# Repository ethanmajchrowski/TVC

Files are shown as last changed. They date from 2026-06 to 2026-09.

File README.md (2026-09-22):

# Two-Axis Thrust Vector Control Model Rocket

A model rocket featuring a two-axis thrust-vector-control (TVC) system, custom flight computer, embedded control software, and a Python flight simulation for controller development and pre-flight testing.

<!-- ![TVC Assembly](Videos/motion.gif) -->
<div align="center">
  <br>
  <i>Two-axis gimbal actuation test. Both axes are commanded with a sinusoidal function.</i>
</div>

## Project Documentation
This project is documented using a design notebook format, recording engineering decisions, prototypes, testing, failures, and design integration in chronologically organized notebooks. 

| Subsystem | Documentation |
| --- | --- |
| Mechanical | [Mechanical Design Notebook](docs/mechanical/README.md)
| Electronics | [Electronics Design Notebook](docs/electronics/README.md)
| Simulation | [Simulation Design Notebook](docs/simulation/README.md)
| Testing | [Testing & Validation](docs/testing/README.md)

A note on testing: most testing is documented in the related design log, so the testing subsection will be lightly used and possibly removed later.

---

## Project Overview

This project is an experimental model rocket designed around an active two-axis thrust-vector-control system. Rather than using aerodynamic control surfaces, the vehicle controls its attitude by mechanically redirecting motor thrust.

The system consists of:

* A lightweight two-axis TVC gimbal
* XIAO ESP32C6 flight computer running MicroPython
* MPU6050 IMU and BMP280 barometer
* Servo-based gimbal actuation
* Python flight-dynamics and control simulation
* SolidWorks mechanical design and 3D-printed prototypes

The project is being developed incrementally, with mechanical design, simulation, electronics integration, and ground testing preceding flight testing.

---

## Current Status

### Completed

* [x] Two-axis TVC gimbal mechanical design
* [x] SolidWorks parts and assembly
* [x] PETG gimbal assembly
* [x] XIAO ESP32C6 flight computer integration
* [x] MPU6050 IMU integration
* [x] BMP280 barometer integration
* [x] Servo actuation and gimbal bench testing
* [x] Initial Python flight simulation
* [x] PID control implementation in simulation

### In Progress

* [ ] Final rocket body design
* [ ] Flight simulation
* [ ] Sensor fusion
* [ ] Electronics documentation
* [ ] Controller tuning and hardware validation
* [ ] Integrated ground testing

### Planned

* [ ] Full-system ground test
* [ ] First controlled flight
* [ ] Flight data collection
* [ ] Post-flight data analysis

---

## Technical Specifications

| Parameter | Current Specification |
| --- | --- |
| Target liftoff mass | ~250 g |
| Motor | D12-5 target; E12-6 under consideration |
| Maximum TVC angle | Approximately ±30° |
| Flight computer | Seeed Studio XIAO ESP32C6 |
| Firmware | MicroPython |
| IMU | MPU6050 |
| Barometer | BMP280 |
| Gimbal actuation | MG90S Servo motors |
| Gimbal axes | 2 |

Specifications are subject to change as the vehicle design and simulation are refined.

---

## System Architecture

The system is divided into three primary components:
<div align="center">
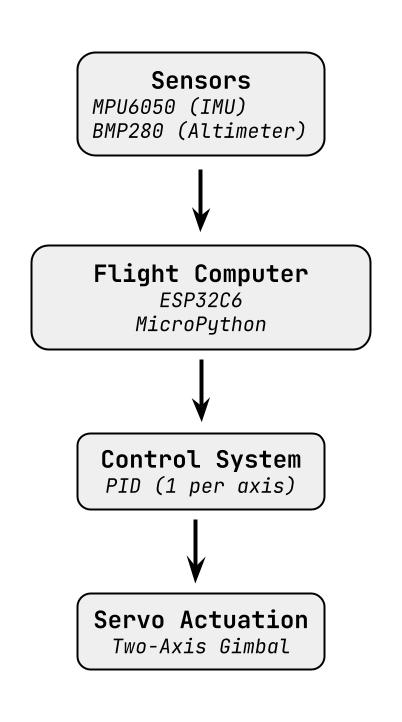
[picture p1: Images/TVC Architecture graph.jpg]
  <br>
</div>

---

## Flight Simulation
[Subsystem Page](docs/simulation/)

Flight Simulations planned to be compiled in MATLAB with Simulink. These will simulate the rocket's PID controls as well as physical status in flight, allowing PID constants to be tuned and verified before first flight.

---

## Embedded Hardware

The flight computer uses a XIAO ESP32C6 running MicroPython.

### Sensors

* **MPU6050** — inertial measurement
* **BMP280** — barometric altitude measurement

### Control

Servo actuators are commanded using PWM outputs from the ESP32C6. The embedded control software is intended to use sensor measurements to determine vehicle attitude and command the TVC servos accordingly.

Sensor-fusion and closed-loop hardware control are currently under development, and will follow this closed-loop flow:

<div align="center">
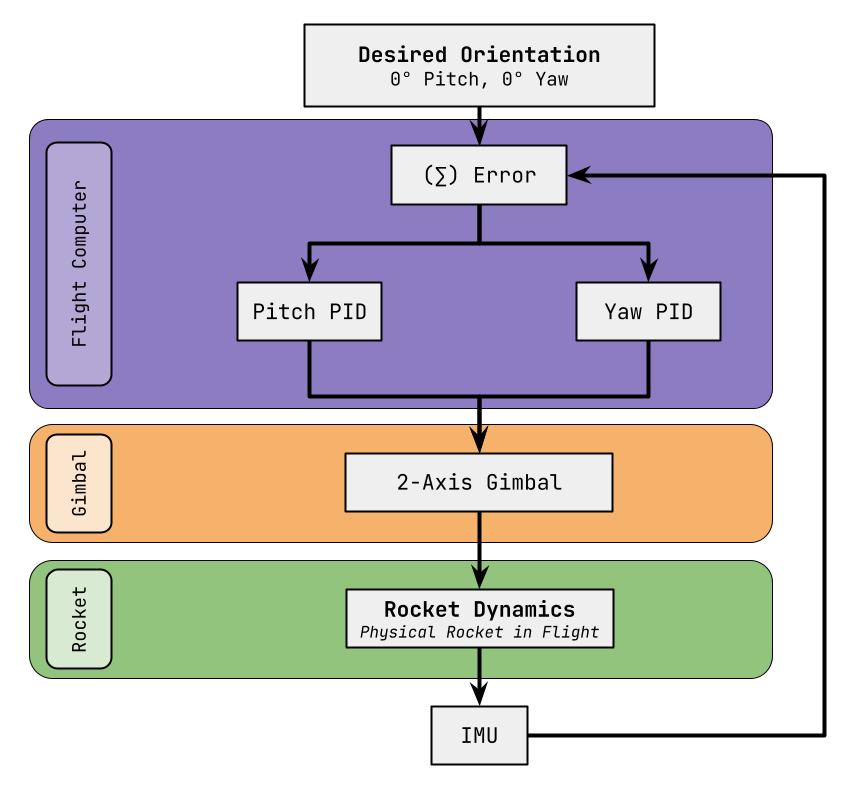
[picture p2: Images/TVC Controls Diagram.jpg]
  <br>
</div>

### Data Logging

Telemetry is currently logged to the flight computer's internal storage. The target logging rate is approximately 100 Hz, although the final rate will be determined through testing.

---

## Electronics

The flight computer is assembled on perfboard around a XIAO ESP32C6.
The design prioritizes simplicity and modularity during the prototype phase, allowing sensors and actuators to be replaced or repositioned without redesigning a PCB.

Additional documentation available in [Electronics Documentation](docs/electronics/)

---

## Repository Structure

```text
TVC/
├── docs/
│   ├── electronics/
│   ├── mechanical/
│   └── simulation/
├── CAD/
│   ├── Parts/
│   └── Assemblies/
├── Electronics/
├── Embedded/
├── Images/
├── Simulation/
└── notes.md
```

| Directory | Contents |
| --- | --- |
| `CAD/` | SolidWorks parts, assemblies, and mechanical design |
| `docs/` | Subsystem-specific documentation |
| `Electronics/` | Electronics schematics and hardware documentation |
| `Embedded/` | MicroPython flight-computer software |
| `Images/` | CAD renders, diagrams, and project photographs |
| `Simulation/`  | Python flight simulation and control software |
| `notes.md` | Development notes and design history |

---

## Development History

This project is being developed iteratively, with mechanical prototypes and simulation informing subsequent hardware revisions.

Major design iterations and test results will be documented here as development continues.

---

## Gallery

### TVC Assembly

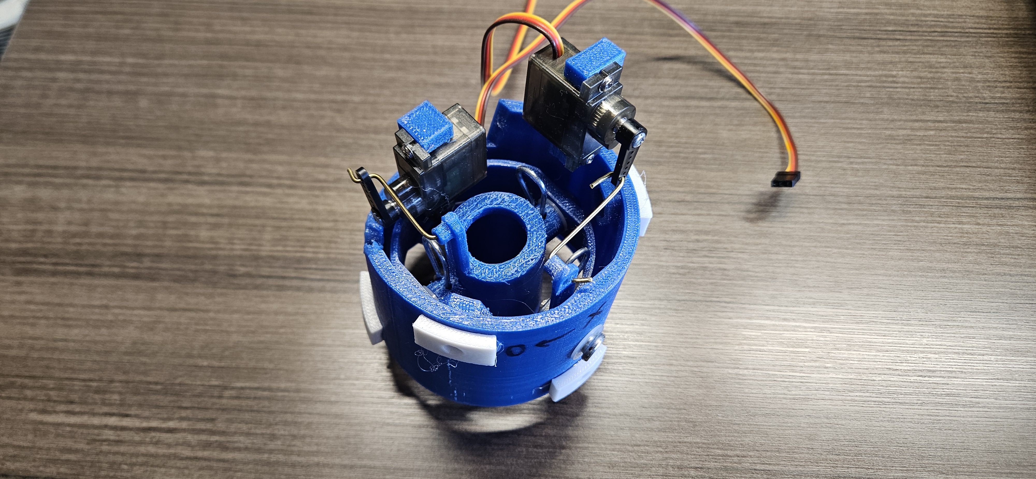
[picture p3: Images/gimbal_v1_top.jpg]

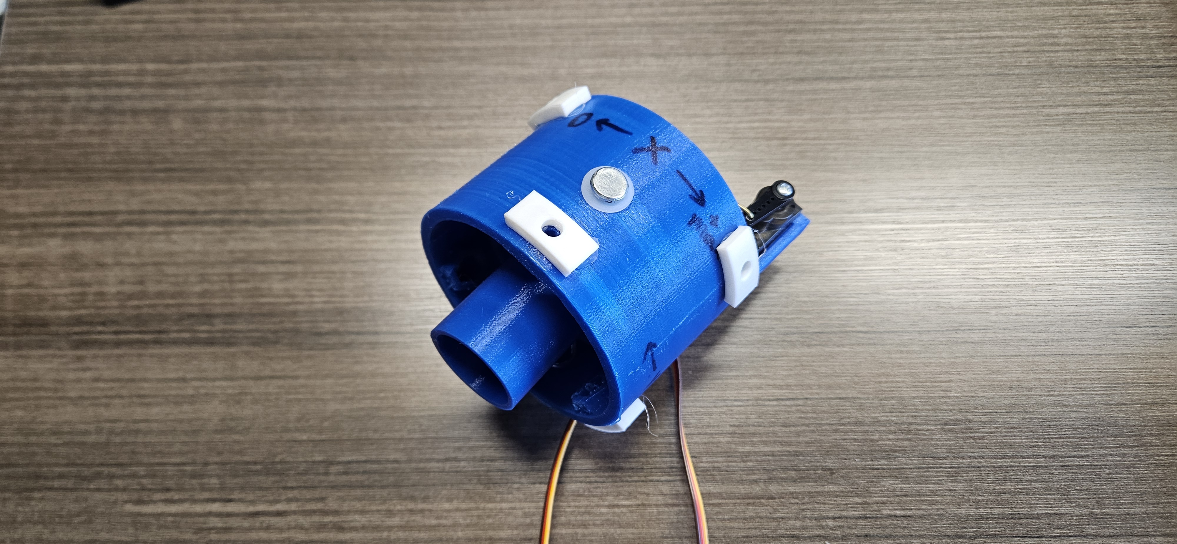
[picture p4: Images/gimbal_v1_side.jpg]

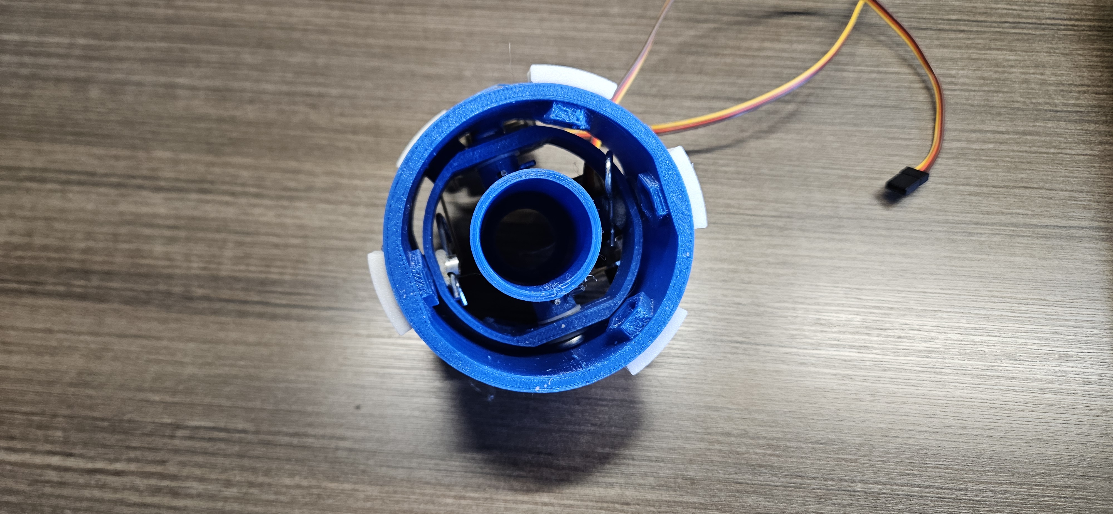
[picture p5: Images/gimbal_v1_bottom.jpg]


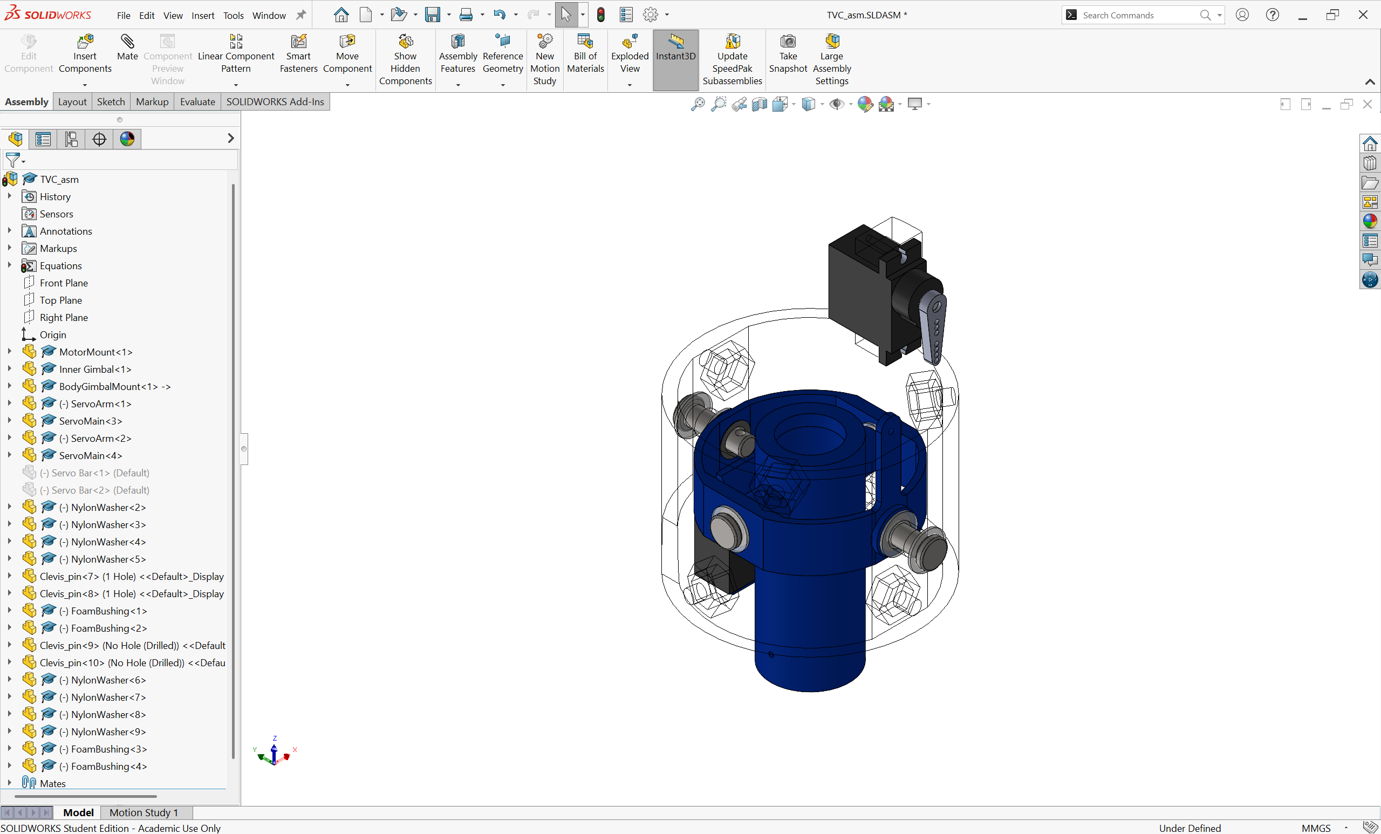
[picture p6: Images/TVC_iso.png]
TVC Isometric


*Full TVC assembly with the outer gimbal mount shown transparently.*

### Cutaway Views

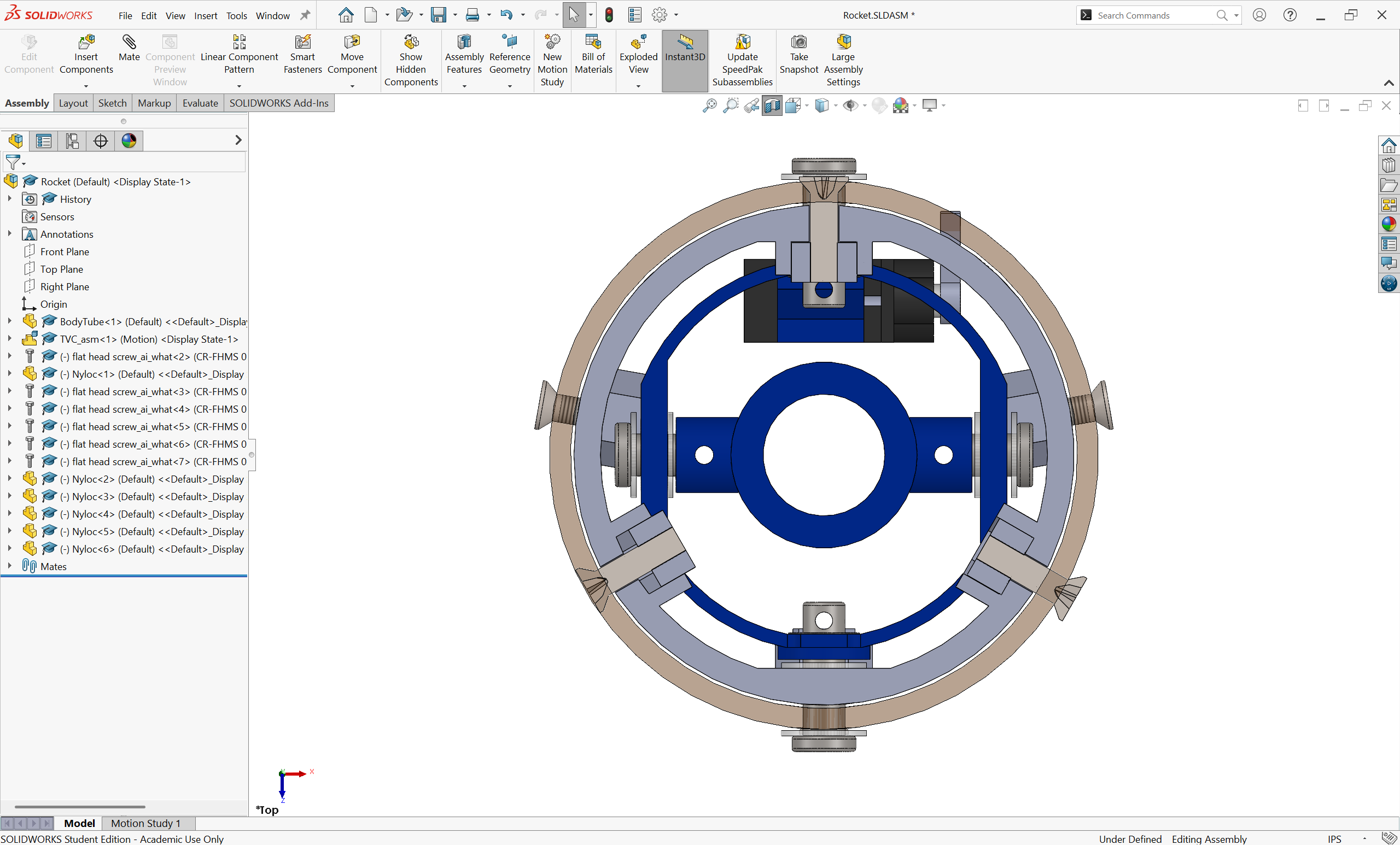
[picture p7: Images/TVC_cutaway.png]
TVC Mount Cutaway


*Gimbal mount cutaway.*

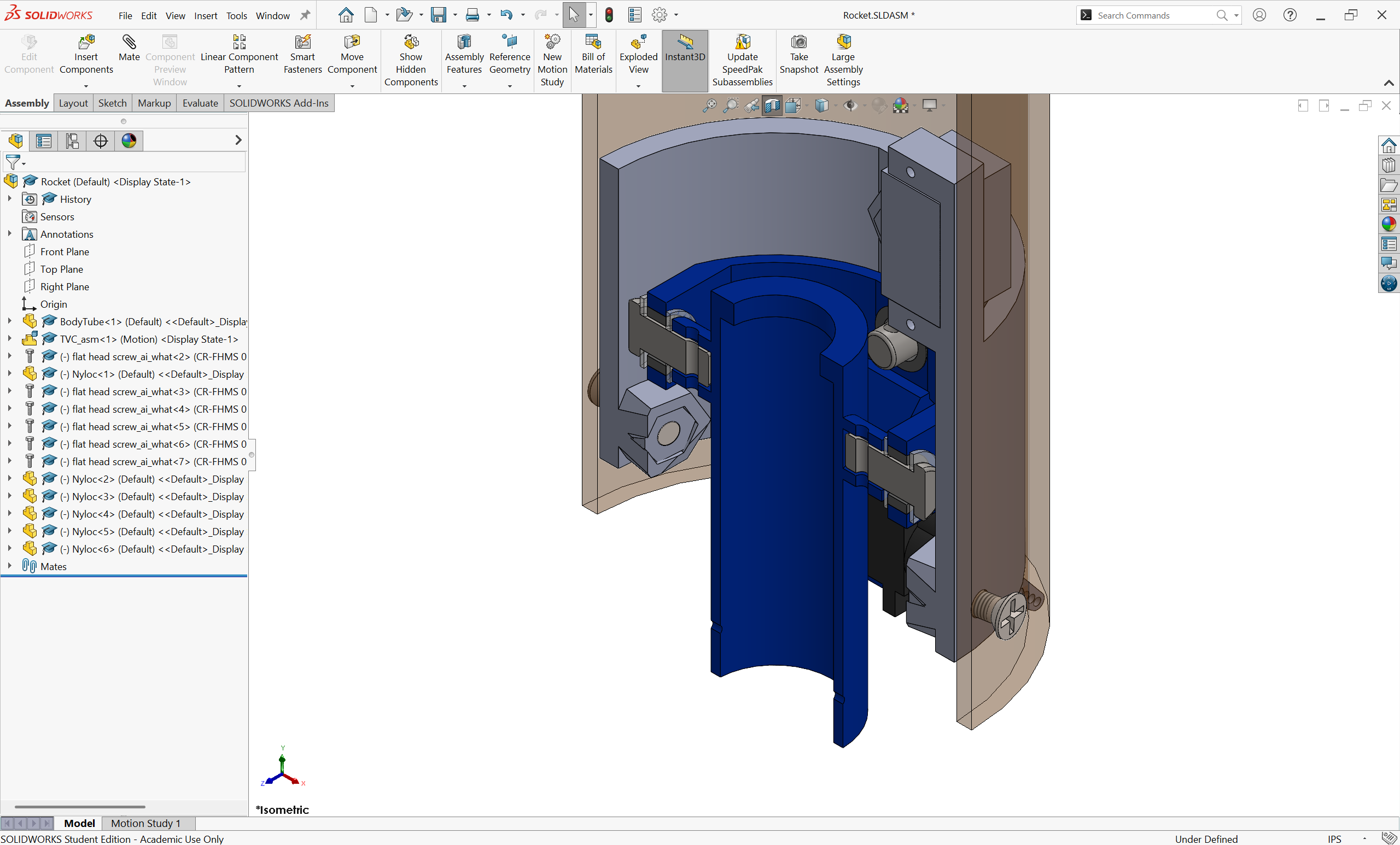
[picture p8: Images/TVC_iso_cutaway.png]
TVC Isometric Cutaway


*Isometric cutaway showing internal components and pivot hardware.*

### Hardware
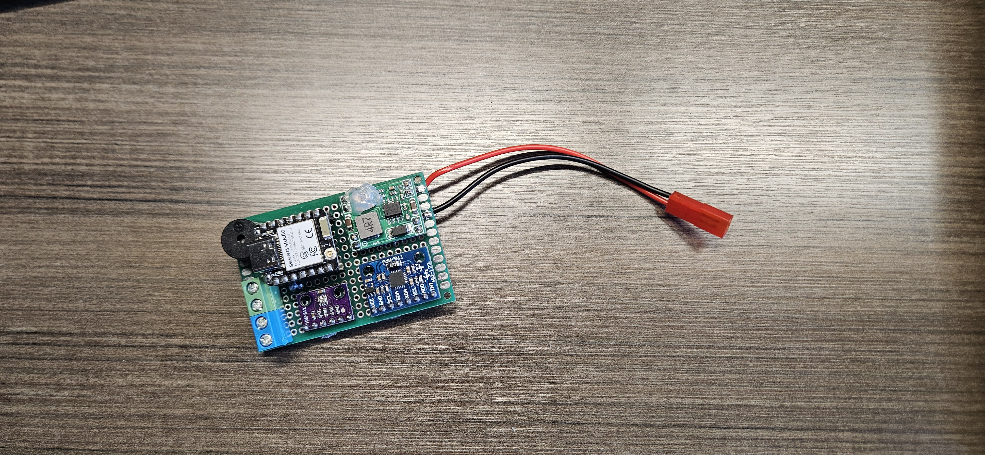
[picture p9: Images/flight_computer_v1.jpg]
Flight Computer Top

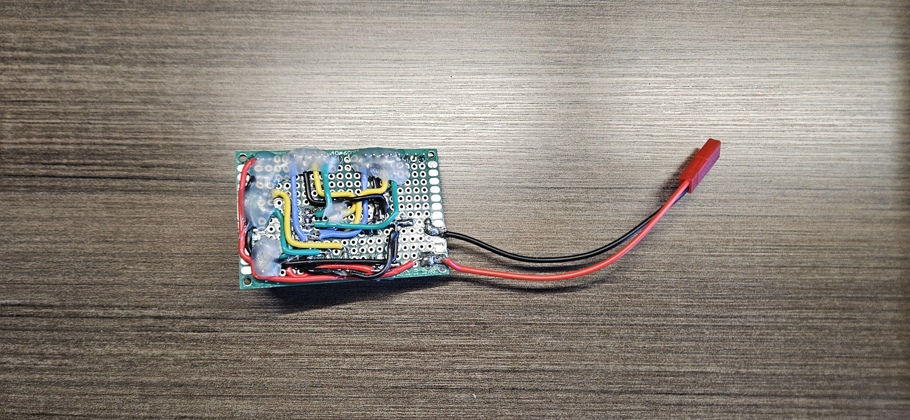
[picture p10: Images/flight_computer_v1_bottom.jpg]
Flight Computer Bottom


---

## Project Status

This is an active development project. Mechanical design, electronics integration, simulation, and control development are ongoing, and the vehicle has not yet completed controlled flight testing.

**Project To-Do**
*CAD/physical design:*
- [ ] Flight computer sled
  - [ ] Determine accessible mounting strategy for flight computer mounting hardware
- [ ] Finalize nose cone design
- [ ] Finalize body tube dimensions and mass properties
- [ ] Bulkhead
  - [ ] Determine suitable material for avionics bulkhead
  - [ ] Determine accessible mounting strategy for bulkhead
  - [ ] Determine motor ejection charge venting strategy

*Electronics:*
- [ ] MOSFET testing for ejection charge
- [ ] Ejection charge perfboard
- [ ] Documentation
  - [ ] Write about overlooking need for ejection charge

*Simulation:*
- [ ] OpenRocket finalize model
  - [ ] Figure out how to simulate rocket with artificial stability to bypass fin requirements
  - [ ] Run OpenRocket simulations to determine maximum altitude
- [ ] MATLAB physical simulation + control tuning

*Testing:*
- [ ] Thrust simulation 
  - [ ] CAD gimbal mount
  - [ ] CAD motor mount adapter for drone motor
  - [ ] Determine if rotary encoders for gimbal mount would be useful
- [ ] Ejection charge Nichrome testing
  - [ ] Ensure rapid heating
  - [ ] Check battery and electronics health
- [ ] Gimbal true angle min/maxes.

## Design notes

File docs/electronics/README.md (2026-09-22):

[← Back to project README](../../README.md)
# Electronics

## Design Requirements
The flight computer needs to:
- Read inertial measurements
- Measure barometric altitude
- Control two TVC servos
- Log flight data
- Fit within the available rocket body
- Be lightweight and serviceable
- Log data for post-flight review

---

## Entry 01 - Initial Design
Test sensors and construct a breadboard-based prototype of flight computer to verify all components and wiring architecture. Determine list of components to be included on final design.

### Design
The hardware present on the flight computer was primarily chosen due to previous possession of all sensors and controllers. These included:
- MPU 6050 IMU
- BMI 160 IMU
- BMP280 Barometer
- ESP32 XIAOC6 Microcontroller
- Arduino Nano Microcontroller

A pack of perfboard bases contained 40x60mm boards and 50x70mm boards. For size footprint, smaller was better for this project, so the 40x60mm board was targeted. 

Deciding on hardware was relatively simple: 
- The ESP32 has a much smaller footprint (21x17.5mm) versus the Nano (45x18mm), making it more suitable for the small size footprint of the targeted board.
- BMI 160 is a more modern sensor with less noise and more accurate readings than the MPU 6050.
The BMP280 was the sensor I had on-hand for altitude measurements.

The ESP32 will communicate over I2C to the IMU and altimeter, allowing both chips to only require 4 pins total on the ESP32. The ESP32 only has 10 data out pins.
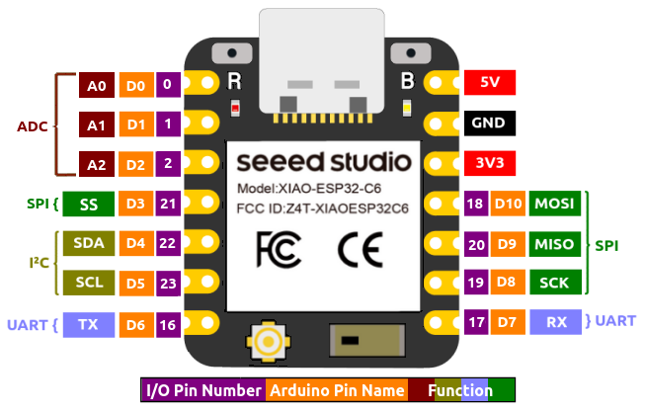
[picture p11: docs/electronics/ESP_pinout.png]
ESP Pinout


The wiring diagram is as follows:
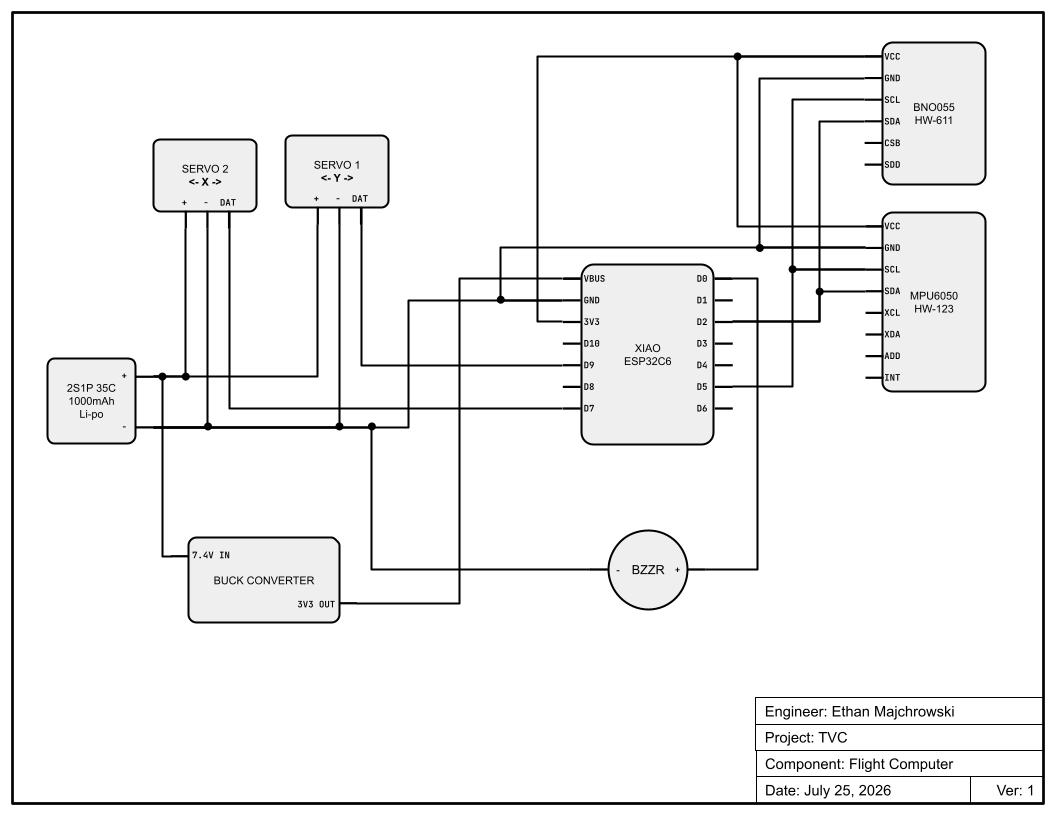
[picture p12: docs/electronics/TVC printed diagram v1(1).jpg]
Circuit Diagram


The ESP32 has a data line to both servos, which are then connected to the battery for power. The entire circuit including the battery shares a common ground. 

The battery for this build was chosen due to it's light weight and small profile. Large LiPos are too heavy and have excess capacity than needed for this build. For flying the flight computer without servos, a smaller battery could be substituted in for a smaller footprint. Since the chosen battery is 7.4V, a buck converter is needed to drop this to 5V for the ESP32 to input.

The initial buck converter chosen is a LM2596 DC to DC buck converter with a 3.0-40V to 1.5-35V adjustable range. However, these modules are large and bulky, so a more modern MP1584EN 4.5V-28V input to 0.8V-20V output adjustable converter was chosen. 

LM2596: 43.2 x 21.2mm
MP1584EN: 22.3 x 17mm

The converter has a potentiometer present to adjust the output voltage. This was set using a multimeter to confirm an output voltage of 5V.

A buzzer is also included in the design to allow for status communication when the rocket is assembled and ready to launch.

## Entry 02 - Perfboard Assembly
After all components were assembled and tested on a breadboard, they could be assembled on a perfboard. This uses holes to mount through hole components, so breakout boards and other large components can easily be soldered. 22 AWG single core wire was used to route connections between the components. The gauge was chosen to be stiff and not easily tangle or fall out of place after soldering. Single core wire is more likely to make one solid connection when soldered vs. stranded wire where a loose strand could make a faulty connection and short the board out. 

## Entry 03 - Software
The ESP32 runs MicroPython as firmware and runs one main code file. Python was chosen due to my proficiency in the language, and that this project is not one focused on learning programming concepts. Using PID control from robotics, a PID class was brought in to simplify development and reuse existing code. 

Existing libraries are used to communicate over I2C to the sensors & servos, and a pin is defined for the buzzer. These libraries allow the board to communicate with the sensors with an easy-to-use API. 

```py
class Pins: # Create pin mappings for easier reference based on physical printings on ESP32
    D0, D1, D2 = 0, 1, 2
    D3, D4, D5 = 21, 22, 23
    D6, D7 = 16, 17
    D8, D9, D10 = 19, 20, 18

# Setup I2C using builtin MicroPython module
SDA = Pin(Pins.D2)
SCL = Pin(Pins.D5)
i2c = SoftI2C(sda=SDA, scl=SCL, freq=100000)

# Sensors
# BMI180: 
  # https://github.com/DanielBustillos/bmi160-micropython-driver/tree/main
  # Authored by Daniel Bustillos
# BMP280: 
  # https://github.com/dafvid/micropython-bmp280
  # Authored by David Stenwall

imu = BMI180(i2c)
bmp = BMP280(i2c, use_case=BMP280_PRES_OS_16)

print(f"devices set up! i2c scan: {i2c.scan()}")

# Servos and maximum degrees
x_servo = Servo(Pins.D7)
x_servo_max = 100
y_servo = Servo(Pins.D9)
y_servo_max = 130
buzzer = Pin(Pins.D0, Pin.OUT)
```

The entry point for the code uses a master `FlightController` class, which exposes a `run()`function for the main code (`boot.py`) to run when the board is powered up. MicroPython runs boot.py on every power up, so any code in there will run immediately. For launches, setup and run code will be placed here.

Software to-do:
- [ ] Implement state machine to interpret ready, ascent, coast, apogee, and descent.

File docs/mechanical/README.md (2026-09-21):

[← Back to project README](../../README.md)
# Mechanical Design

Mechanical components were designed in SolidWorks with an emphasis on minimizing mass while maintaining sufficient stiffness and range of motion for the TVC mechanism.

The gimbal components form two perpendicular rotational axes, allowing the motor thrust vector to be redirected in both pitch and yaw.

**Current Development Status:** V1 gimbal assembled and ready for airframe integration.

--- 

# Design Log

## Entry 01 - Research & Prototyping
### Goal
Research existing solutions for inspiration and to develop an understanding of gimbal mechanism.

### Research
Thrust Vector Control (TVC) is a solution employed by nearly all 'real' rockets. Rather than using fins to stabilize a rocket's flight, the thrust itself can be gimbaled to exert a torque, allowing active control to keep the rocket stable.

TVC is not limited to rocketry. It can also be found on aircraft and drones. In rocketry it is especially helpful because it allows us to control the orientation of a craft without relying on fins. Fins keep a rocket stable but rely on high dynamic pressure. A simple computation for dynamic pressure (q) is $q = \frac{1}{2} \rho v^{2}$, where $\rho$ is the fluid density of the air and $v$ is the velocity of the rocket. For large rockets with low thrust to weight ratios, this velocity is very low, leading to a proportional decrease in dynamic pressure. 
*[NASA](https://www.grc.nasa.gov/www/BGH/dynpress.html), [Richard Nakka](https://www.nakka-rocketry.net/RD_fin.htm)*

The goal for this rocket is to use TVC to actively stabilize the rocket, without passive stability mechanisms like fins. To do so, a gimbal needs to be constructed. The first step was to research existing solutions to this problem.

TVC has been done on the model scale before, and designs exist to construct your own. However, for this project the design will be custom. To get an idea for how to design this gimbal, I first explored existing solutions:
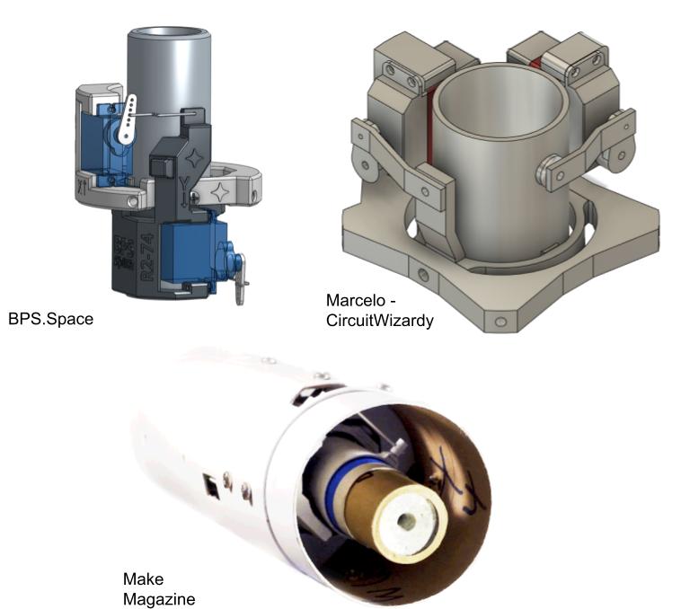
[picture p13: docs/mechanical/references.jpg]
Images of existing TVC CAD designs


These solutions highlight a few major design points:
- The mounts typically use servo motors to orient the motor
- There are 3 main components: the outer mount which fixes to the airframe, an inner gimbal which provides one axis of freedom, and a motor mount which has the second axis of rotation. 
- Sometimes, the airframe is modified to make clearance for servo arms or moving components. 

### Understanding the Gimbal
The gimbal is the most important part of this design, so it is important to develop a strong intuition for what it is doing in the mechanism, and how the parts move in relation to each other. To do this, I developed a basic prototype in SolidWorks to mock up what the motion of the gimbal should look like. 
Gimbal mock-up gif
This mockup had some issues with constraints and motion, but it provided the baseline for understanding how the inner gimbal and motor mounts should move together. One thing that was important to understand was that one servo is fixed with the airframe, and the other moves with the inner gimbal mount. This allows the axis of rotation of the second servo to follow along as the first servo moves. 

When creating this mockup, a few things were noted:
- The static servo will need a connection higher up on the inner gimbal than where the gimbal pivots, to allow room for the servo mounting
- The largest challenge with this design will be clearance to allow as much range of motion as possible. 

## Entry 02 - Designing the Gimbal
### Goal
To create a more complete, manufacturable version of the gimbal mount that can be assembled for installation into the rocket.

### Design Requirements
Taking the preliminary mockup of motion into account, the design was developed oriented based on the axes of rotations. Working outwards in, the first part to be designed is the gimbal mount which is attached to the airframe.

Requirements:
- Provide two independent rotational axes
- Allow approximately ±15° of TVC movement
- Maintain the motor's position relative to the rocket centerline
- Provide mounting locations for two servos
- Avoid interference between the gimbal, servo arms, and airframe
- Be lightweight enough for the vehicle's mass budget
- Be manufacturable using desktop 3D printing

### Outer Gimbal Mount
The outermost component is the motor gimbal mount. This design follows the internal diameter of the airframe and has a mounting bracket for the servo motor. There is also a hole for the hardware to connect to the inner gimbal mount.
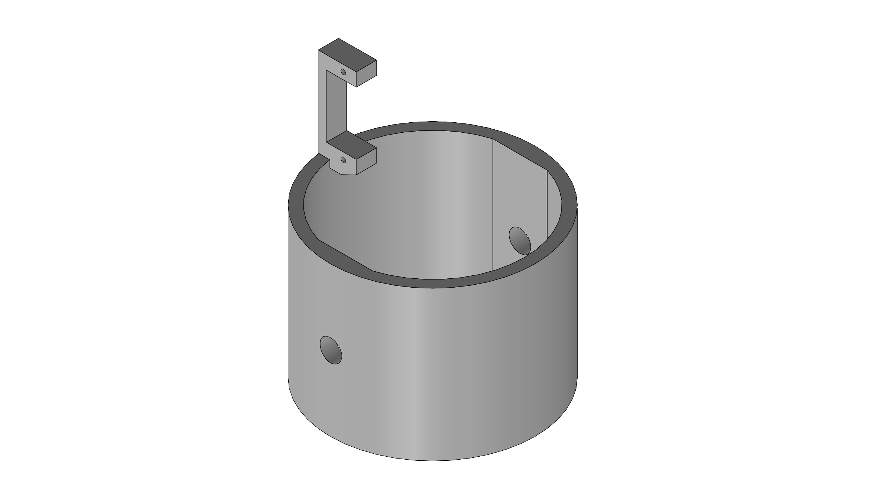
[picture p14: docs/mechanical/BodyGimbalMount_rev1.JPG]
Motor Gimbal Mount


This initial geometry follows the mock up and establishes the overall interface between the airframe and the gimbal, providing a starting point to model and attach sub components.

Design for mounting hardware also needs to be considered. This will be done using bolts and nylon locking nuts for security. 
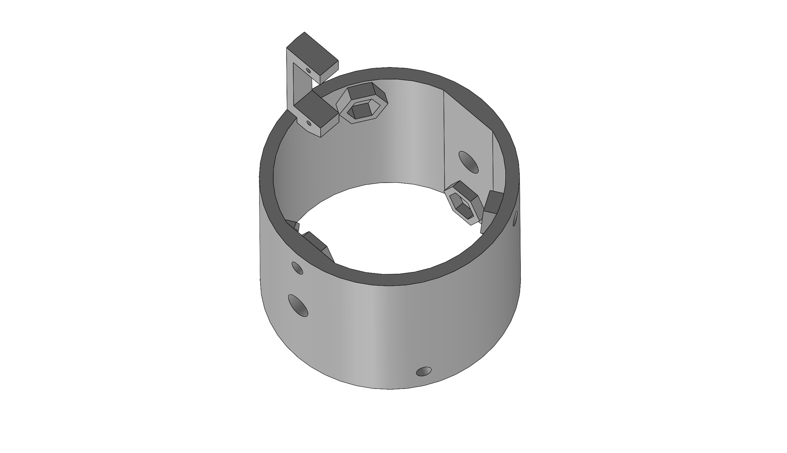
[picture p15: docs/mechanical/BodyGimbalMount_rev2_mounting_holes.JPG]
Motor Gimbal Mount

By including a hexagonal profile on the interior of the mount, the nylon nuts can be held in place with a small amount of glue and then be easily assembled with the physical slot holding the nut in place. This decision will allow for easier final assembly, where access within the gimbal is difficult.

### Inner Gimbal Mount
The inner gimbal provides the second rotational axis and carries the motor mount. Its geometry was driven primarily by three constraints:

1. Maintaining the required rotational range
2. Providing a mounting location for the second servo
3. Maintaining clearance from the outer mount throughout the range of motion

The inner gimbal was designed after the basic two-axis mechanism had been established in the preliminary SolidWorks mockup, as well as the design of the outer gimbal mount. This involved top-down part design which made it easy to define dimensions and verify clearance as geometry was added.
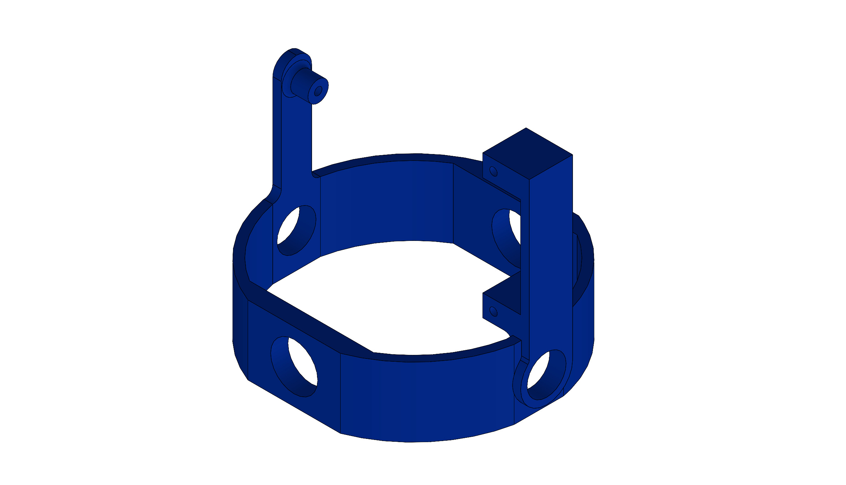
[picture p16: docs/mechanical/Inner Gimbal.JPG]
Inner Gimbal CAD

This part includes 4 axis holes for connection to the outer mount and the inner gimbal. It includes an arm to link to the outer mount servo, and another servo mount to hold the second servo.

### Motor Mount
The motor mount is the final layer of the gimbal that interfaces with the rocket motor and provides the final axis of rotation for the TVC mount. The mount needs to interface with standard Estes "Large" motors which have a 24mm OD. The initial motor-mount print used a 24.5 mm internal diameter, but the motor fit was too tight for practical assembly. The CAD dimension was increased to 25 mm for the subsequent revision. The resulting printed part measured approximately 24.75 mm internally and provided the desired fit.
The thrust is transmitted through the gimbal rotation hardware, so the motor mount includes a long sleeve to facilitate this. The sleeve around the hardware also is required because the presence of the motor makes it impossible to have hardware slot through the walls of the mount. 
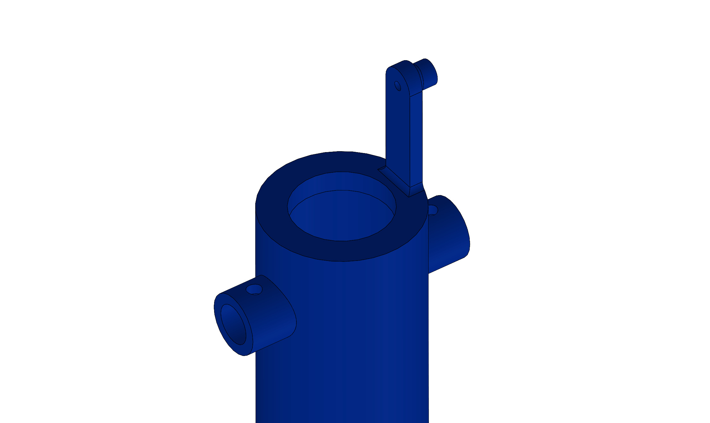
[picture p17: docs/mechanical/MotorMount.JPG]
Motor Mount CAD

A connecting arm was also included similar to the inner gimbal to allow a connection between the motor mount and servo arm. 

### Assembly Plan
The assembly of the gimbal is difficult because it requires smooth motion between 3 interconnecting parts. Dowels and rods were considered, but a clevis and cotter pin were decided on. These allow rotation around an axis (due to the clevis pin) but lock translation across that axis (due to the cotter pin).

By combining pins and the holes provided within the design we can assemble the gimbal like so:
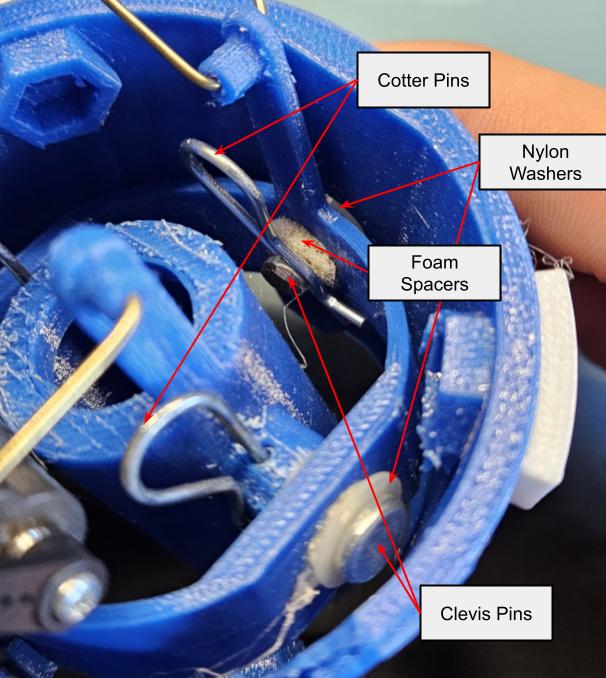
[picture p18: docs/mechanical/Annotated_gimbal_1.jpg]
Gimbal Assembly Annotated

The foam spacers help the clevis pins remain centered within the axial holes on the gimbal parts, and the nylon washers help facilitate smooth rotation between components. The assembly hardware can be seen in these cut-outs of the CAD:

TVC Mount Cutaway
TVC Isometric Cutaway

### Clearance & Range of Motion
By combining the gimbals into an assembly in SolidWorks, we can examining the range of motion of the gimbal. In initial inspection of this assembly, the clearance for the inner servo arm was very low due to the outer gimbal mount. To solve this, a slot was removed from the 3D printed component and a slot is planned to be cut in the airframe.

By moving each axis independently until a collision occurs, we can determine the approximate range of motion of the assembly:

X Axis:
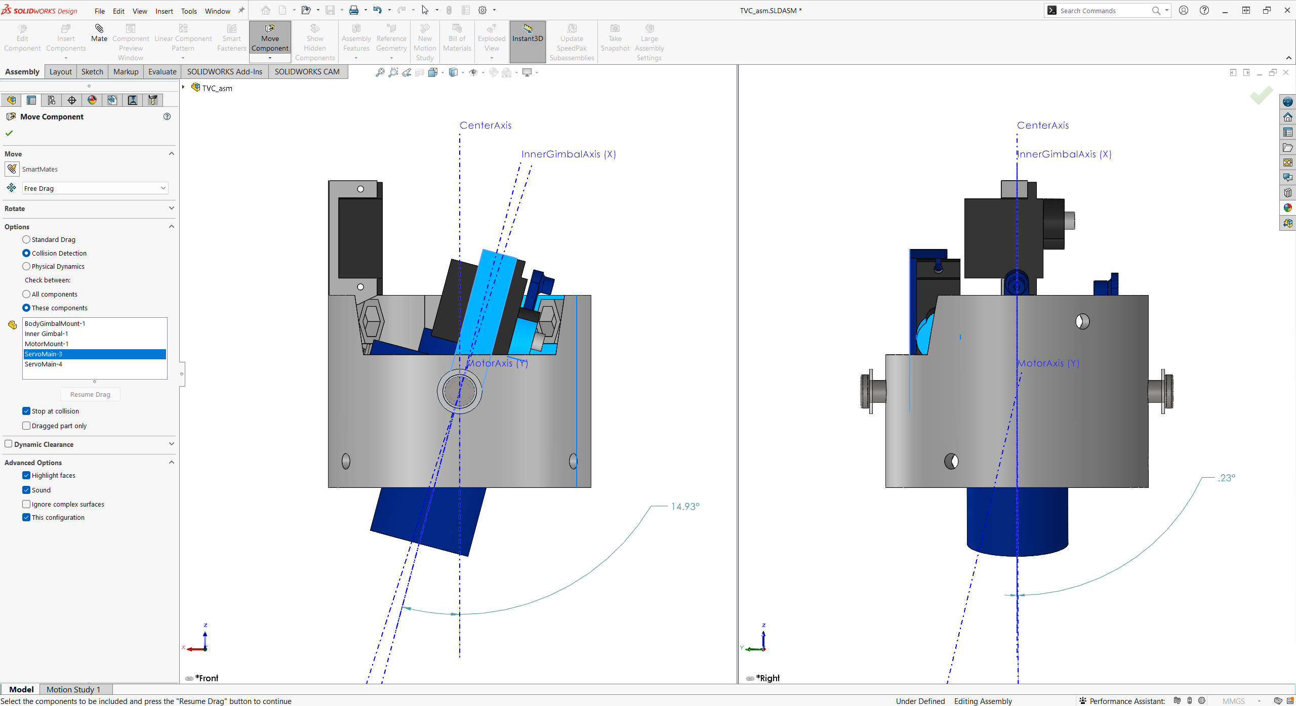
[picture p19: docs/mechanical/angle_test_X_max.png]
Gimbal Angle Testing X Max

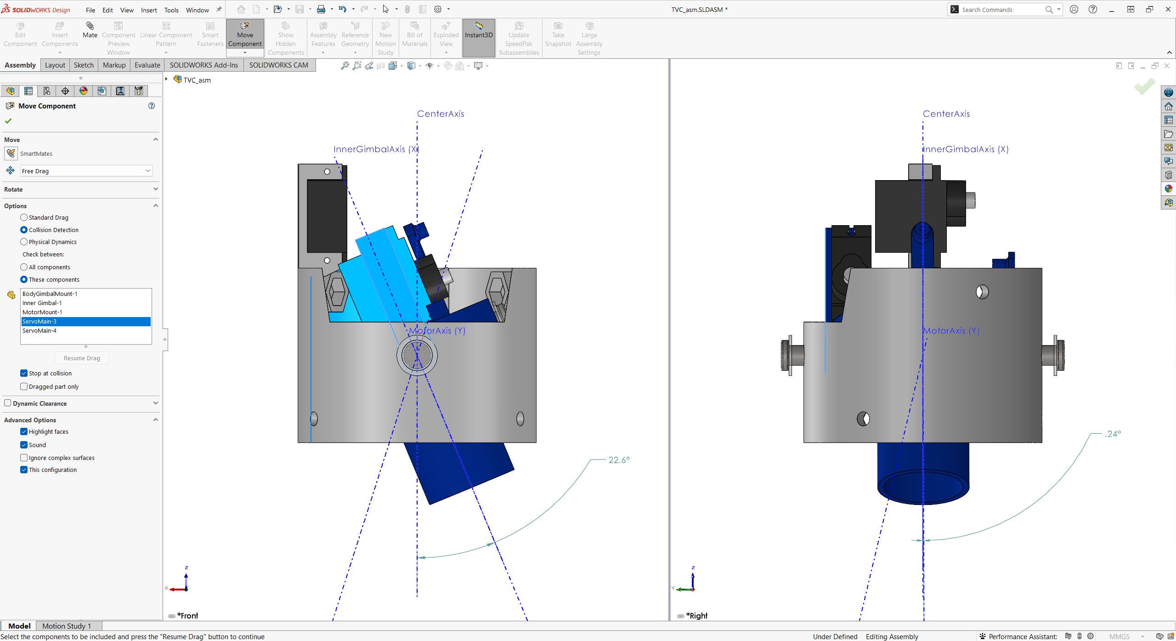
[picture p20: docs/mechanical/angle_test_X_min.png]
Gimbal Angle Testing X min

Y Axis:
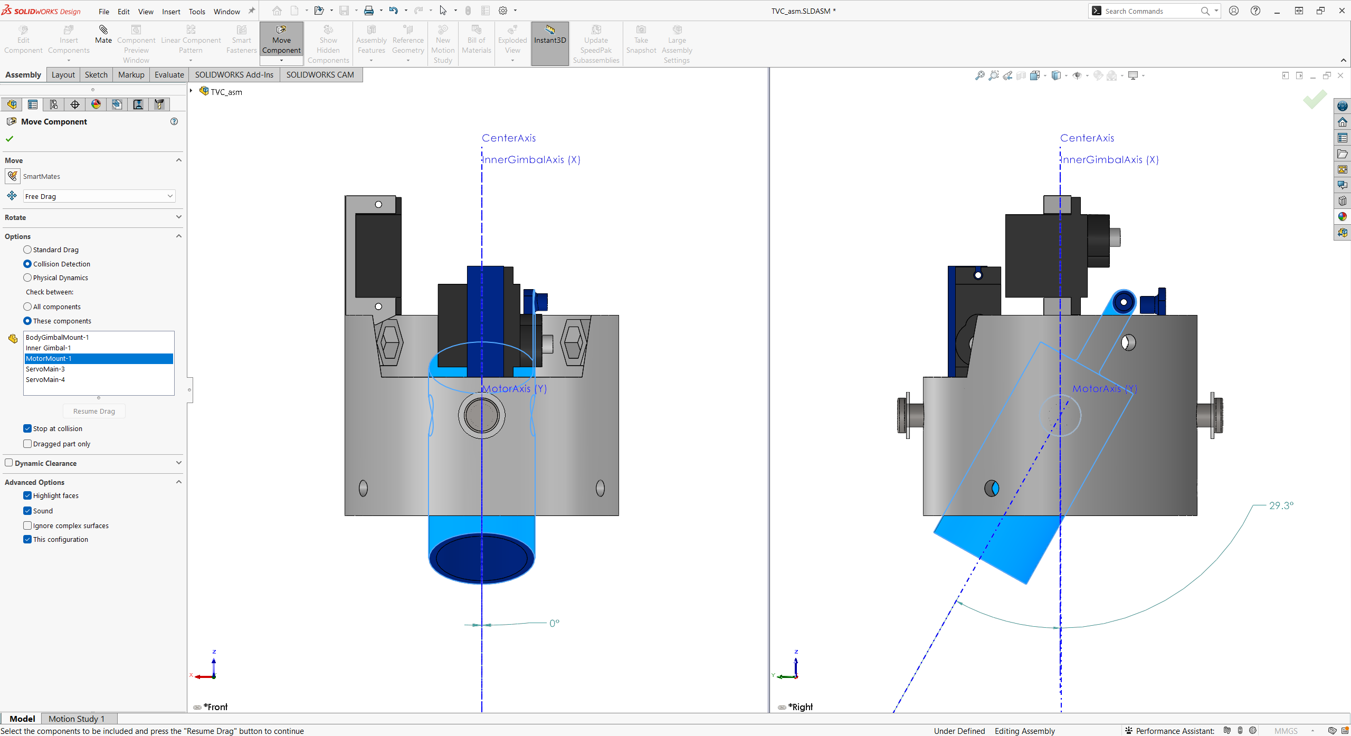
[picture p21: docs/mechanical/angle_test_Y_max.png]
Gimbal Angle Testing Y Max

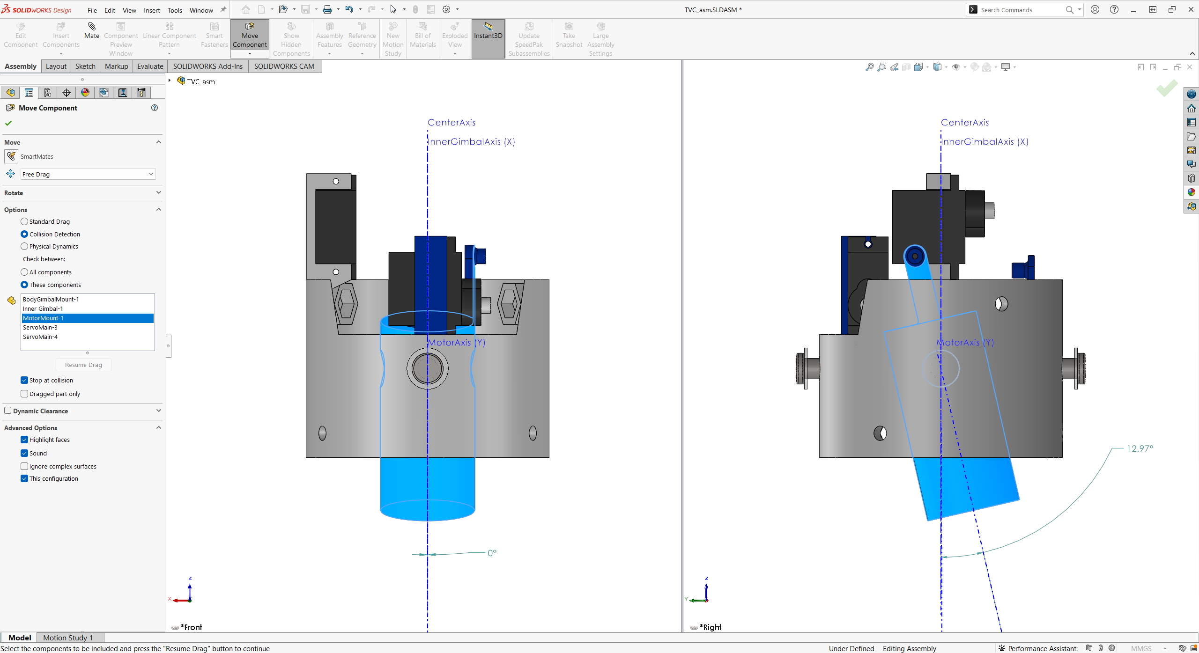
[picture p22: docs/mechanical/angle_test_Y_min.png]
Gimbal Angle Testing Y min


Based on these values, we can know the *approximate* range of motion for each gimbal axis:
| Axis | Min | Max |
| ---- | --- | --- |
| X | $-15^{\circ}$ | $+22.5^{\circ}$ |
| Y | $-30^{\circ}$ | $+13^{\circ}$ |

The limiting symmetric range is therefore approximately ±13°, although the mechanism has greater asymmetric travel in each axis. For the current design, ±15° is being treated as the nominal target range and will be validated through physical testing. With the physical assembly, modifications will be considered to increase the Y-axis limiting range by 2°.

### Materials
The initial prototype was printed and assembled in PLA Black. Due to concerns over brittleness, the current assembly is printed in PETG blue. PETG was selected for the current assembly because its greater ductility compared with PLA makes it less susceptible to brittle fracture during handling and mechanical loading.

### Final Assembly
Final Assembly Image
<div align="center">
<i> Final construction of V1 gimbal, including mounting hardware, servos, and servo linkage bars. </i>
</div>

### Initial Modifications
Shortly after initial construction, it was determined that there was significant limitation in the X - axis rotation. To fix this, the slot in the outer gimbal was expanded to make room for the inner gimbal servo arm.
Removed material highlighted in red.
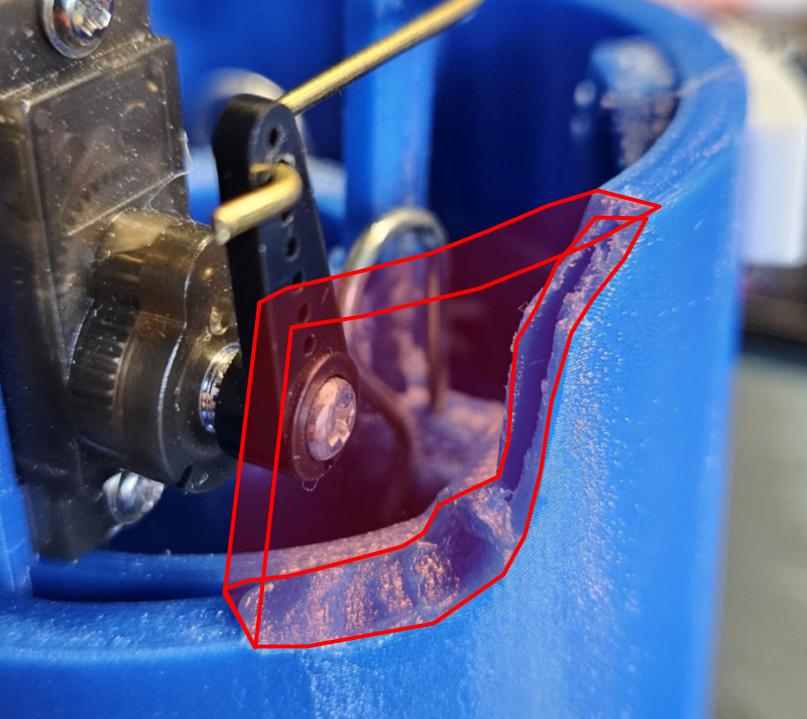
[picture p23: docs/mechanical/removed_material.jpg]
Removed Material Image

This adjustment has been updated in the CAD to reflect material removal and prevent the need from manually performing this operation in the future.

## Entry 03 - Clearance Inspection
To-do: Measure physical assembly gimbal angle limits and compare to CAD assembly theoretical limits.

## Entry 04 - Assembly V1 Evaluation
After the first assembly of the gimbal mount, observations were collected and the design was evaluated.

**Observations**
- The design has noticeable play in both rotation and translation, especially within the joint between the inner and outer gimbal components.
  - This interface likely comes from excess tolerance in the holes in the outer gimbal, allowing excess motion.
  - The motor mount is more rigid translationally but still has play rotationally. On both axes this most likely originates from imperfect linkages between servo and gimbal. 
- Upon application of upwards pressure to the motor mount (similar to the force that will be exerted by the motor) the inner gimbal translates vertically approximately 1.5mm. Gimbal motion due to servos *does not appear* to be limited by this force, but this will need to be verified with thrust simulation.
  - This allowed motion appears to flex portions of the inner gimbal outwards, most likely due to the material properties of PETG.
<div align="center">
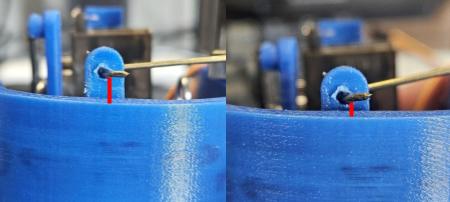
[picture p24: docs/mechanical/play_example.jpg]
     <br> <br>
</div>

- Clearance holes for airframe mounting bolts are too small, and hexagonal inserts for nylon locking nuts are too small.

<br></br>

**Potential Failure Modes**
- Component cracking
  - Due to the high force applied by the motor and inherent nature of plastic FDM printing, a major point of failure would be cracking or shattering of the gimbal mount during flight. This risk has been reduced by printing in PETG, but is not eliminated.
  - This could potentially be tested by determining the max force applied by the motor and simulating that force on the gimbal and inspecting for cracks or fractures.
- Excessive gimbal deflection
  - Excessive rotation of the gimbal due to the servo motors *could* occur, but is unlikely. Servo travel will be limited in software based on the measured mechanical range to prevent commands from driving the mechanism into known interference points.
- Pin movement
  - The play in the cotter pins introduces concern as another point of failure, but it is unlikely as the pins and clips themselves are steel. A failure of the plastic frame is much more likely.
- Servo linkage failure
  - This is a more likely point of failure for the design. The linkages between the servo arms and gimbal components could break or slip free during flight leaving the rocket without control over an axis of rotation, which would likely be catastrophic. In order to mitigate this, the ends of the linkages are bent around the connection points in a U shape to prevent disconnection.
- Mount deformation
  - Due to the heat generated by the rocket motor, the motor mount is subject to potential thermal deformation during flight, which could unpredictably degrade attitude control. While PETG has a processing melting range of 230–260°C, its structural limits are governed by its Heat Deflection Temperature (HDT) of 65–75°C (149–167°F), at which point the material softens under mechanical load. [[JLC3DP](https://jlc3dp.com/blog/petg-temperature-resistance)] Specific motor casing profiles during burns are unavailable, but thermal failure is expected to be low because the total exposure time (burn duration) is minimized, delaying localized hot spots. Post-flight inspections will monitor the mount for signs of softening, structural creep, or warping.

**Planned Revisions**
- Reduce extra clearance on clevis pin mounting holes in outer gimbal
- Move motor mount servo connection bar radially outwards to be more in line with the face of the servo to reduce play.
- If thermal deformation is found to be an issue, a cardboard or plastic liner can be used as a thermal barrier between the motor casing and mount to reduce deformation on subsequent flights.
- Increase hole and hexagonal insert diameter for airframe mounting hardware. These can be drilled out and press fit for this assembly, however.
- Add interior shoulder to inner gimbal, similar to outer shoulder on motor mount to reduce play at the clevis pin.
<div align="center">
  <image src="planned_shoulder.jpg"><br>
  <i>Notated planned shoulder addition: existing shoulder in green, location for additional shoulder in red.</i>
</div>

## Entry 05 - Airframe Design

### Initial Airframe

The initial plan for the airframe was to use the 3 in. ID cardboard tubing from my Tripoli Level 1 certification rocket. While this tubing is strong, its mass made it impractical for this project. The tubing weighed approximately **15.5 g/in.**, meaning that a roughly 2 ft. section would already exceed the maximum recommended lift weight of the selected motor before accounting for the motor, electronics, TVC assembly, and other hardware.

This prompted an investigation into lighter airframe materials.

### Fiberglass Investigation

One option considered was purchasing a pre-made fiberglass airframe. These were ultimately ruled out primarily due to cost and shipping. For example, a 30 in. section of 3 in. fiberglass tubing was priced at over $60. *[Wildman Rocketry](https://wildmanrocketry.com/collections/fiberglass-1/products/g12-3-0)*

As an alternative, I investigated manufacturing my own fiberglass body tube. This involved sourcing and preparing a mandrel, wrapping fiberglass around the mandrel, saturating the material with epoxy, and removing the cured tube from the mandrel.

The process proved to be more time-consuming than expected, particularly during removal of the cured tube from the mandrel. The resulting tube also required repair after removal and trimming. Despite these issues, the finished tube provided a useful comparison point and weighed approximately **11.58 g/in.**

### Lightweight Cardboard Alternative

During this process, I found a lightweight cardboard shipping tube with a **3.2 in. ID and 1.5 mm wall thickness**. At approximately **11 g/in.**, this tube was slightly lighter than the fiberglass tube while being significantly easier to cut, modify, and assemble.

The primary compatibility issue was the diameter of the existing TVC gimbal. The gimbal was designed around a 3 in. outer diameter, leaving a gap between the gimbal and the 3.2 in. ID airframe.

To resolve this, spacers were designed and 3D printed to attach to the outside of the gimbal and increase its effective diameter. The spacers are bonded to the gimbal rather than mechanically fastened because they do not carry the primary structural load. The existing screws retain the gimbal components, while the spacers primarily center the assembly within the airframe.

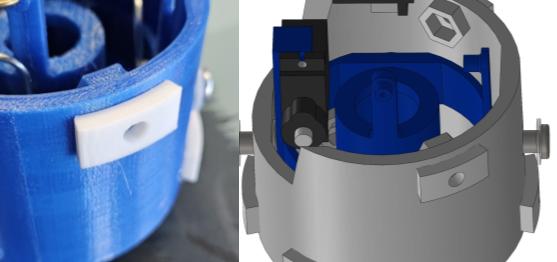
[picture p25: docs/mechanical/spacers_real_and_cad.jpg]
Airframe Spacers


*3D-printed spacers used to adapt the 3 in. gimbal assembly to the larger-diameter airframe.*

### Current Design

The lightweight cardboard tube is currently the preferred airframe material because it provides a favorable combination of low mass, low cost, and ease of fabrication compared with the alternatives investigated.

The final airframe length will be determined after the remaining rocket geometry is finalized in CAD. This will allow the overall vehicle mass to be evaluated before selecting the final length and confirming that the completed vehicle remains within the motor's appropriate performance range.

### Design Comparison

| Airframe Option | Approx. Mass | Advantages | Disadvantages |
| --- | ---: | --- | --- |
| 3 in. cardboard | 15.5 g/in. | Strong, already available | Too heavy for current mass budget |
| Homemade fiberglass |  11.58 g/in. | Lightweight, rigid | Time-consuming to manufacture; difficult demolding |
| Lightweight cardboard | ~11 g/in. | Lightweight, inexpensive, easy to modify | Larger diameter requires gimbal adaptation |

The current design therefore prioritizes the lightweight cardboard tube, with the fiberglass tube serving as an investigated alternative rather than the final material.

---

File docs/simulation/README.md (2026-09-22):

[← Back to project README](../../README.md)
# Simulation

Simulation of the rocket initially began as a custom python program to simulate the gimbal and active control of the rocket. Due to the high complexity associated with writing such a program, this approach was discarded after a time of development. Future simulation will be done in MATLAB, but tuning of the PIDs for the rocket can be done using physical testing.

---

## Python Simulation
The flight simulation was written in Python using `pygame-ce`. It modeled the rocket's translational and rotational behavior and provided a development environment for testing the control system before flight.

The simulation included:

* Acceleration
* Velocity
* Position
* Thrust-vectoring torque
* PID control
* Estimated thrust-to-weight ratio
* Estimated apogee
* Simplified rocket-flight dynamics

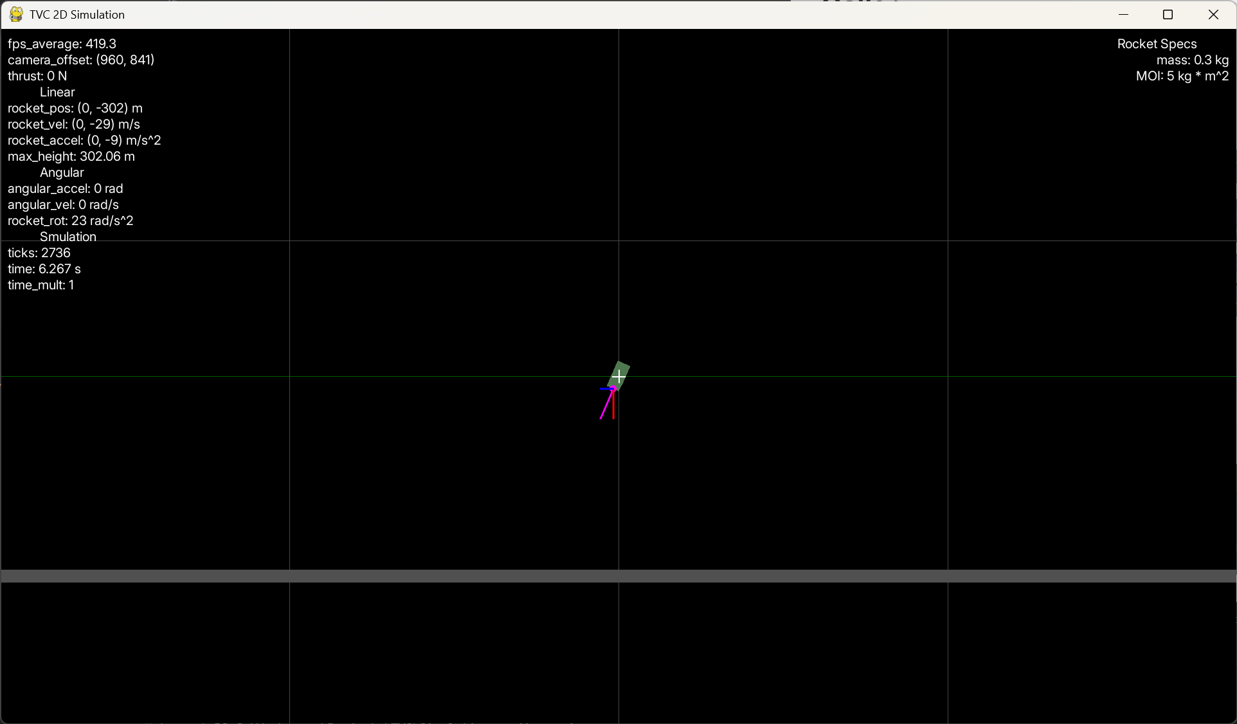
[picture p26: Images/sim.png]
Flight Simulation


*Python simulation interface and rocket-flight model.*

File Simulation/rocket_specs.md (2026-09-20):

# Mass Properties
TVC Mount - 80g
Body Tube (full 5ish feet) - 836.31 g (half -> 418.2 g)
*cardboard body -> 110g at 7in*

*fiberglass body -> 81g at 7in, 139g at 12in*
*surface area of 3in cyl at 24in long: 18.9 sq. ft*
*weight of 8 sq. ft of fiberglass: 144g*

Electronics (estimate): 10g
Battery: 10g
Nosecone: (estimate) 90g

*D motor max lift weight: 283g*
*E motor max lift weight: 397g*

### Leftover data from python simulation configurations 
! May not be correct to physical rocket !
Rocket lenbgth: 43.18 cm.
Mass Properties: 
- Total mass is 0.300 kg
- Undetermined moment of inertia

*Servo assumptions*
Max Actuation: The nozzle/mount can tilt up to 10.0 degrees.
Servo Speed: Actuators move at a rate of 15.0 degrees per second.
Current Angles: Both the initial and target angles start at 0.0 degrees.

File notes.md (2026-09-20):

# Mass Properties

Heavy cardboard Body Tube (full 5ish feet) - 836.31 g (half -> 418.2 g)
14g/in
2 ft = 334.4g

Fiberglass Tube
3in section @ 14g = 4.7g/in
2ft = 112g

D motor max lift weight: 283g
E motor max lift weight: 397g

TVC Mount - 80g
Electronics (estimate): 10g
Battery: 10g
Nosecone: (estimate) 90g

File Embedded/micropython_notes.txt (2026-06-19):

GPIO basics + interrupts
https://docs.micropython.org/en/latest/esp8266/tutorial/pins.html
I2C bus
https://docs.micropython.org/en/latest/esp8266/quickref.html#i2c-bus

Open REPL with PuTTY
- open Device Manager
- find COM port under "Ports (COM & LPT)
- open PuTTY
- switch from SSH to Serial under host name box
- change COM number and set baud rate to 115200 for esp32 micropython

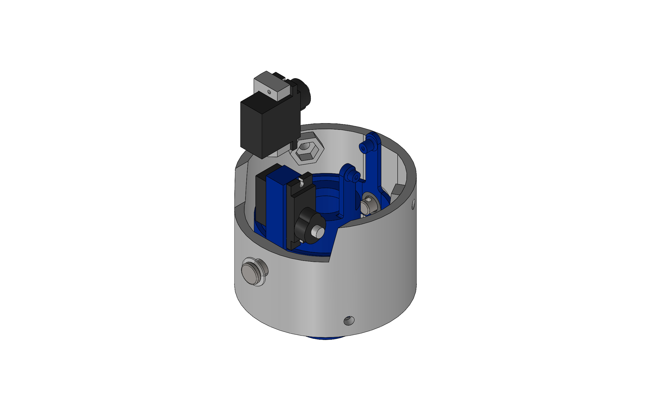
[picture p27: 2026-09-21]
docs/mechanical/full_asm.JPG

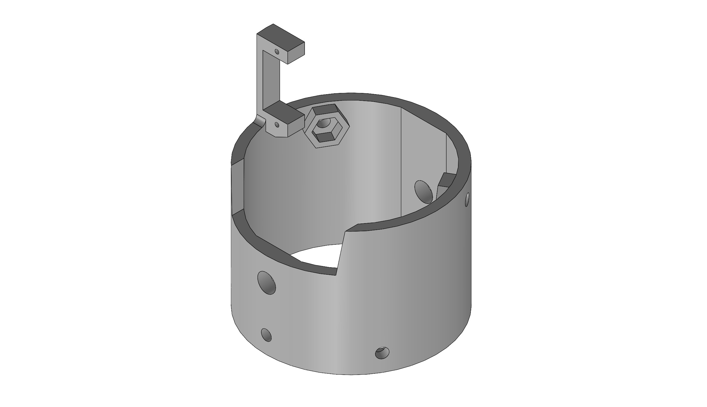
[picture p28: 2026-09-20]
docs/mechanical/BodyGimbalMount_rev3_clearance_cut.JPG

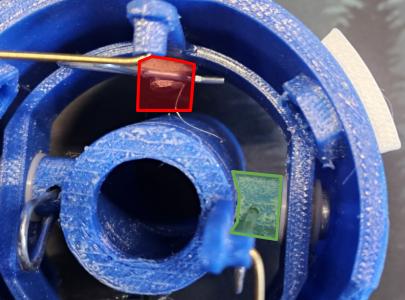
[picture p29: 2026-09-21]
docs/mechanical/planned_shoulder.jpg

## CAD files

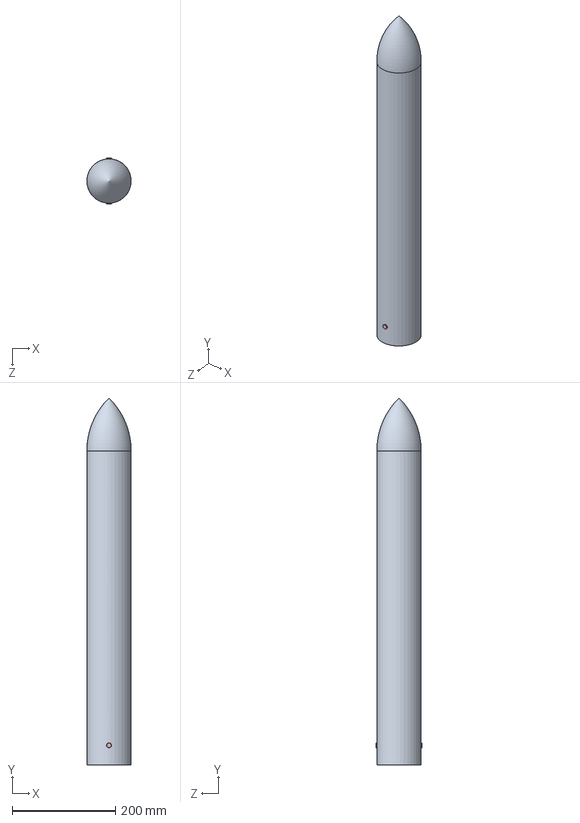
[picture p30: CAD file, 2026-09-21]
CAD/Assemblies/Rocket.SLDASM
86.0 x 712.1 x 89.2 mm
BodyTube
Inner Gimbal
BodyGimbalMount
ServoMain x 2
Clevis_pin x 4
FoamBushing x 4
LargeBodyTubeSpacer x 6
Nyloc x 6
Nosecone

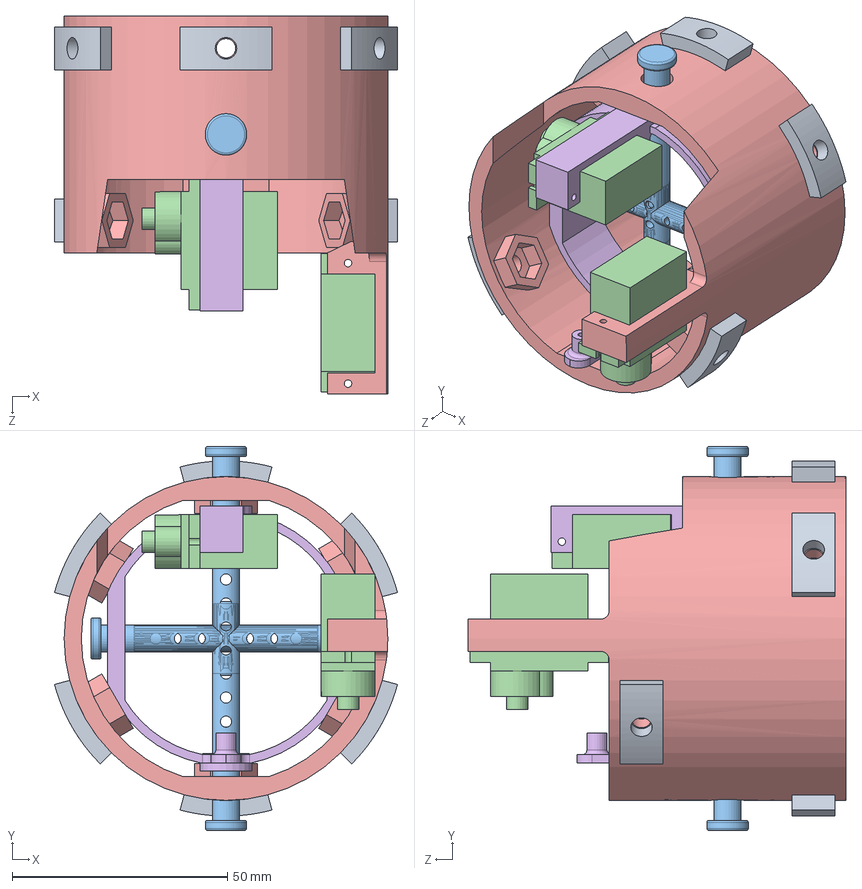
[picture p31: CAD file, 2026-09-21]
CAD/Assemblies/TVC_asm.SLDASM
79.7 x 89.2 x 87.8 mm
Inner Gimbal
BodyGimbalMount
ServoMain x 2
Clevis_pin x 4
FoamBushing x 4
LargeBodyTubeSpacer x 6

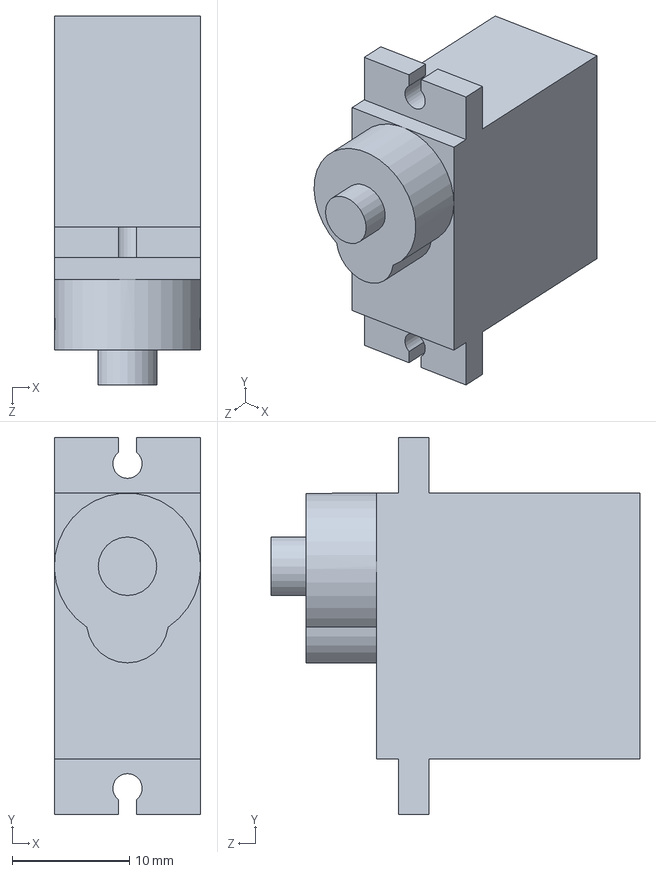
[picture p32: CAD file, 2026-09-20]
CAD/Parts/ServoMain.SLDPRT
12.5 x 32.2 x 31.5 mm

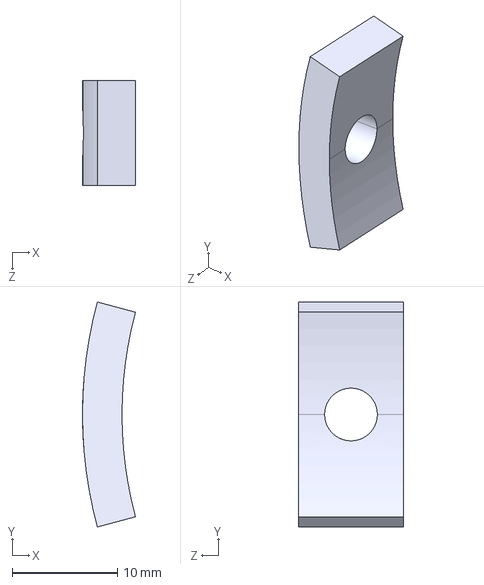
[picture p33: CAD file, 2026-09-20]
CAD/Manufacturing/LargeBodyTubeSpacer.STEP
5.03 x 21.4 x 10.0 mm

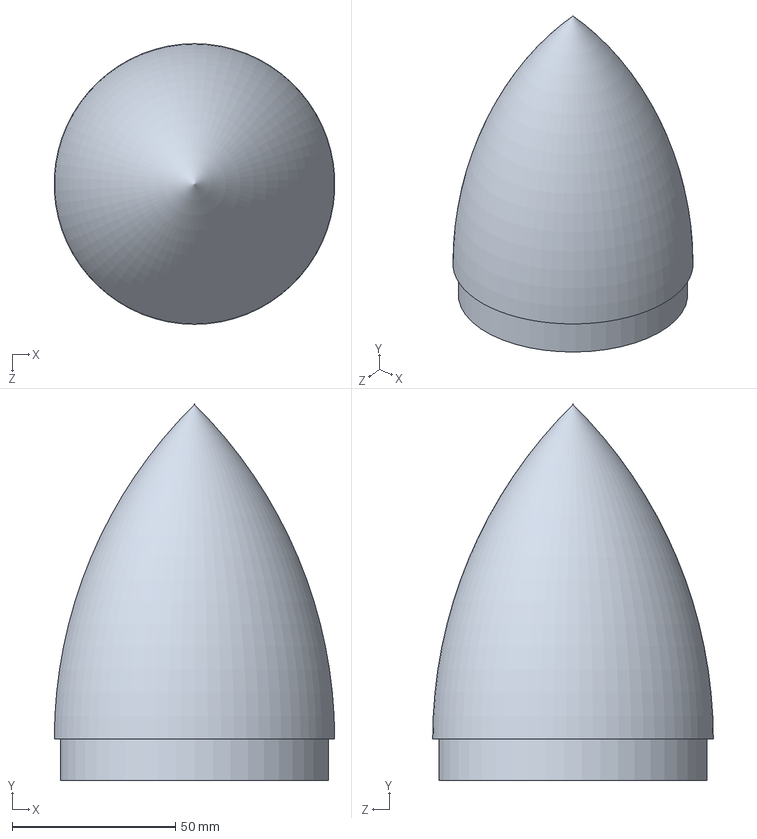
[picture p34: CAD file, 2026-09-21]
CAD/Parts/Nosecone.SLDPRT
85.9 x 115.2 x 86.0 mm

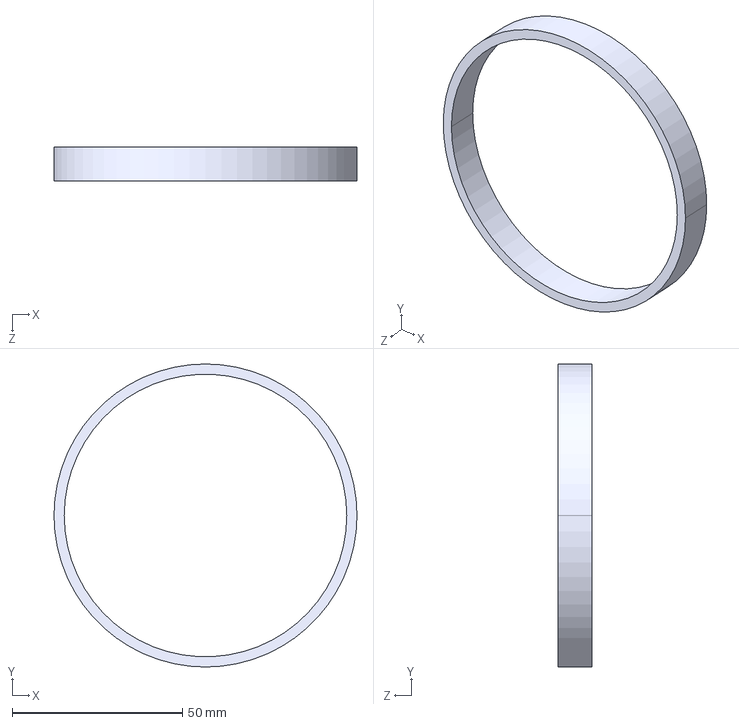
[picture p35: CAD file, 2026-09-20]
CAD/Manufacturing/fiberglass_support_ring.STEP
88.9 x 88.9 x 10.00 mm

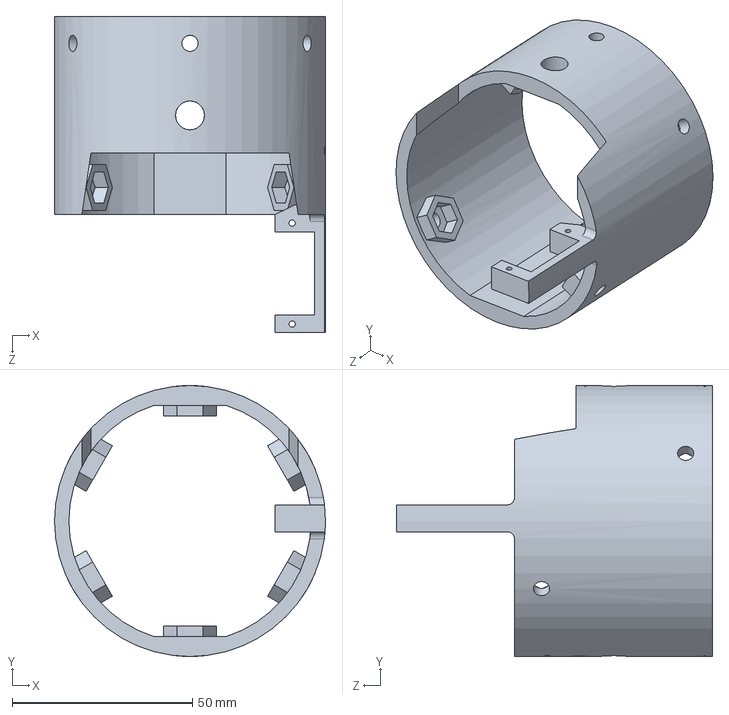
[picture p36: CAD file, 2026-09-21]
CAD/Parts/BodyGimbalMount.SLDPRT
75.2 x 75.2 x 87.8 mm

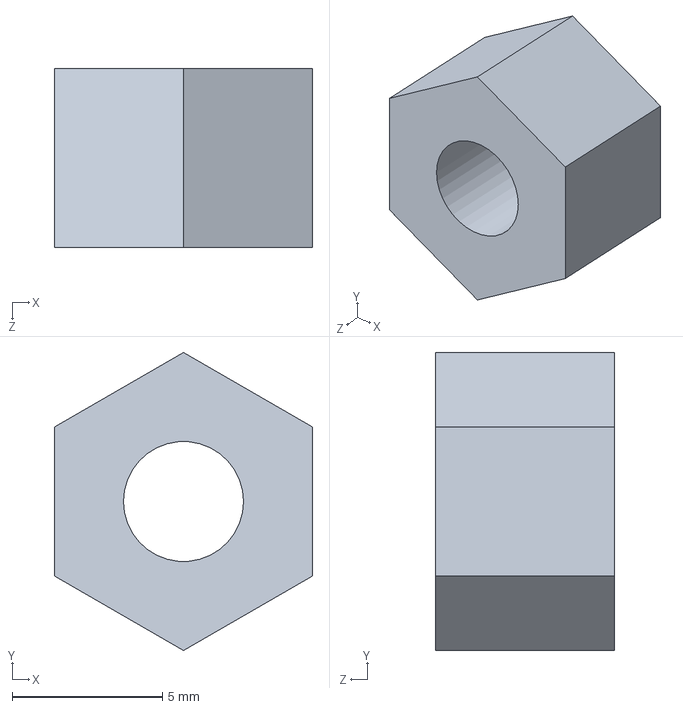
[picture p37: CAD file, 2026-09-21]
CAD/Parts/Hardware/Nyloc.SLDPRT
8.60 x 9.93 x 5.96 mm

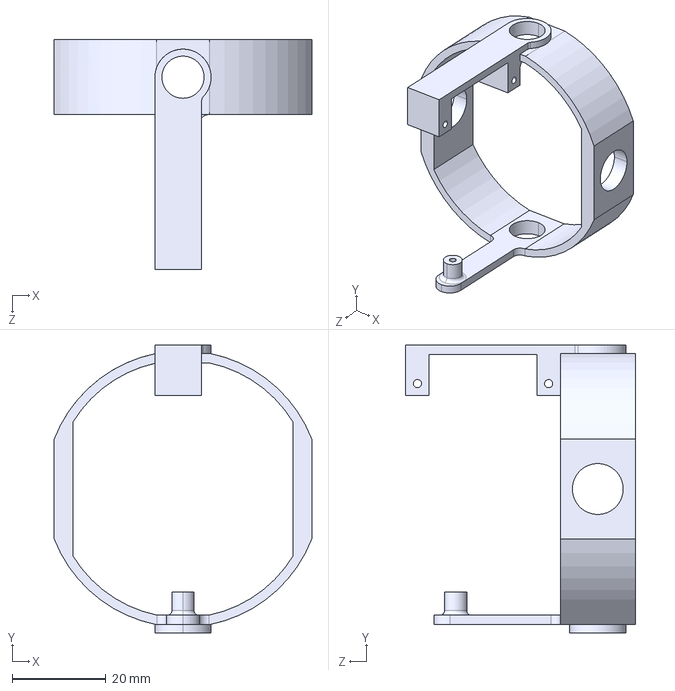
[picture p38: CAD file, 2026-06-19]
CAD/Manufacturing/Inner Gimbal.STEP
55.0 x 61.5 x 49.0 mm

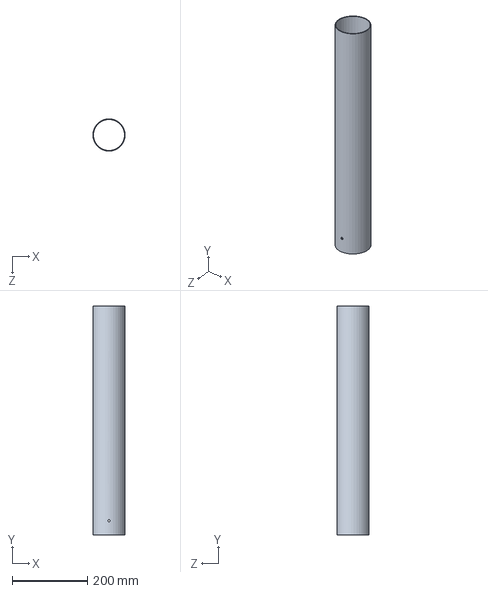
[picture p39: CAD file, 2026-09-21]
CAD/Parts/BodyTube.SLDPRT
85.9 x 609.6 x 86.0 mm

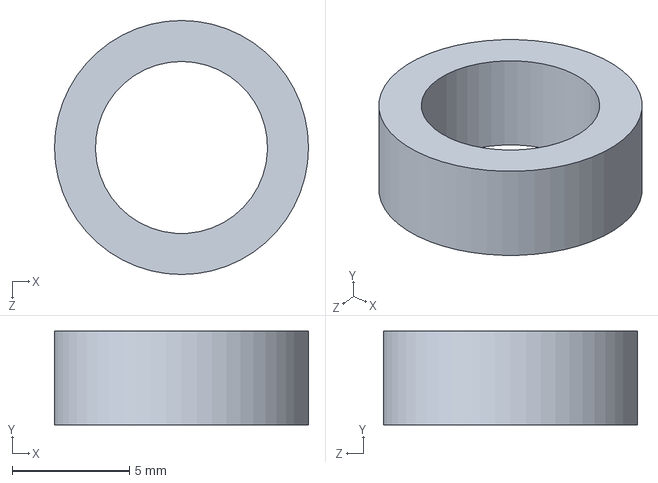
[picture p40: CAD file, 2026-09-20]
CAD/Parts/Hardware/FoamBushing.SLDPRT
10.9 x 4.00 x 10.9 mm

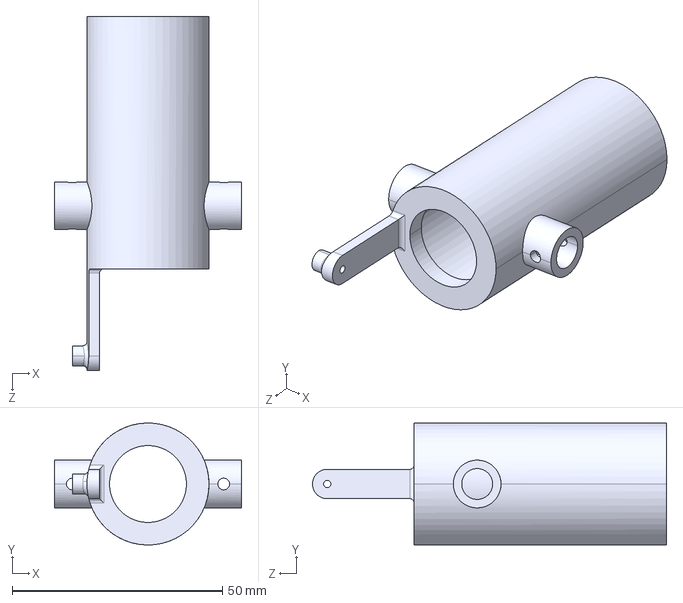
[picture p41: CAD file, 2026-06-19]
CAD/Manufacturing/MotorMount.STEP
44.5 x 29.0 x 84.2 mm

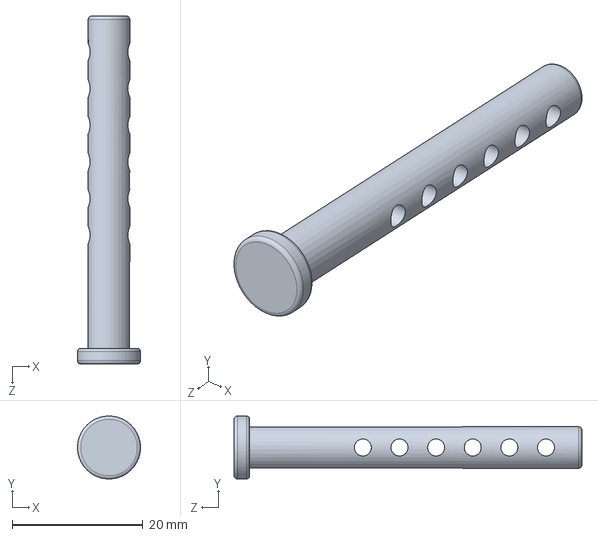
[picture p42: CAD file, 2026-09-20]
CAD/Parts/Hardware/Clevis_pin.SLDPRT
9.63 x 9.61 x 53.2 mm

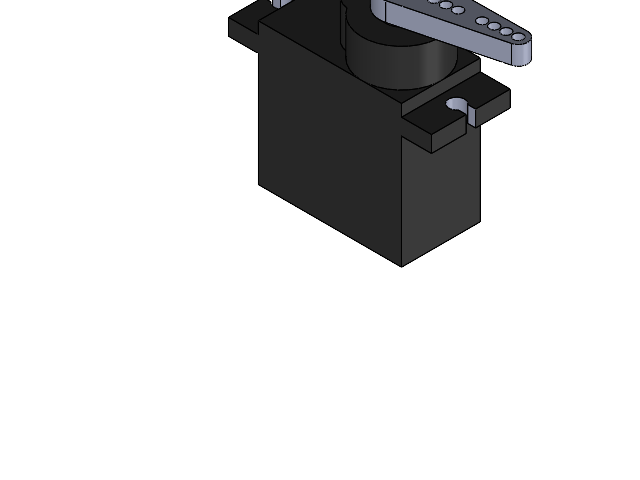
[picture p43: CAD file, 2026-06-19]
CAD/Assemblies/ServoAsm.SLDASM
ServoMain
ServoArm

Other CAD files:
CAD/Assemblies/FlightComputerSled.SLDASM
CAD/Parts/Hardware/LargeBodyTubeSpacer.SLDPRT
CAD/Parts/Inner Gimbal.SLDPRT
CAD/Manufacturing/BodyGimbalMount.STEP
CAD/Parts/Battery.SLDPRT
CAD/Parts/FlightComputer.SLDPRT
CAD/Parts/FlightComputerSled.SLDPRT
CAD/Parts/Hardware/Clevis_pin_inner.SLDPRT
CAD/Parts/Hardware/Clevis_pin_outer.SLDPRT
CAD/Parts/Hardware/MR84-2Z - Deep groove ball bearing.step
CAD/Parts/Hardware/MR84ZZ_bearing.SLDPRT
CAD/Parts/Hardware/NylonWasher.SLDPRT
CAD/Parts/MotorMount.SLDPRT
CAD/Parts/Nosecons.SLDPRT
CAD/Parts/Servo Bar.SLDPRT
CAD/Parts/ServoArm.SLDPRT

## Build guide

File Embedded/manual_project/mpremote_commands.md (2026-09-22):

# REPL / running
mpremote (opens REPL)
mpremote connect <dev> (connect to device)
mpremote disconnect (disconnect)
mpremote repl (enter REPL)
mpremote eval <expr> (evaluate/print expr)
mpremote exec <code> (execute python code)
mpremote run <file> (run local script)
    mpremote run <file> --no-follow (returns immediately and leaves the device running the script in the background)

# Filesystem
mpremote fs ls (list files)
mpremote fs cp <src> <dest> (copy files) (: in front for remote file)
    example: `mpremote fs cp lib/BMP280.py :lib/BMP280.py`
mpremote fs rm <file> (remove file)
mpremote fs mkdir <dir> (create directory)
mpremote fs rmdir <dir> (remove directory)
mpremote fs cat <file> (display file content)

# misc
mpremote mount <dir> (mount local folder)
mpremote soft-reset (soft reset)
mpremote bootloader (enter bootloader)
mpremote mip install <pkg> (install package) 
mpremote devs (list connected devices)

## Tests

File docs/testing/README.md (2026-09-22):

[← Back to project README](../../README.md)
# Testing

## Test 01 - Thrust Simulation
In order to tune a PID properly, the system must be repeatedly tested and values tweaked to achieve the desired result. If the controller introduces oscillation or does not reach the setpoint within a desirable amount of time, the tuning constants must be adjusted. 

This project makes that process uniquely difficult. Due to the nature of rockets, the conditions in which the PID will be performing are difficult to replicate or repeat multiple times. To tune the rocket traditionally, it would have to be launched multiple times while examining the behavior of the control. This is costly and dangerous, as the rocket may not survive without a properly tuned algorithm.

To solve this problem, we can simulate the rocket's thrust using a propellor and drone motor. The plan for this test is to mount the rocket in a static gimbal that allows for rotation around the rocket's COM, then connect a motor and propellor to the motor mount. By spinning the propellor, we can simulate an equivalent thrust on the rocket. This allows us to test the mechanical performance of the gimbal mount as well as tune the control constants for the PID algorithms.

Testing is currently planned for the near future, as soon as the rocket CAD is finalized and initial assembly complete.

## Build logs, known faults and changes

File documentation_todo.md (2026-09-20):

- [ ] Renderings of all solidworks parts for access without solidworks
  - [ ] Any way to link to important assemblies without soldiworks
- [ ]

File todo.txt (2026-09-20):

- Ematch lighting circuit
	- separate perfboard, wired to above / attached below current board
- simulation (matlab?)
- CAD of computer sled
	- computer sled mounting hardware
- Finalize CAD of mounting, get and assemble gimbal mounting hardware

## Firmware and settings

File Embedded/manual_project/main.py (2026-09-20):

# Example code for (GY-521) MPU6050 Accelerometer/Gyro Module
# Write in MicroPython by Warayut Poomiwatracanont JAN 2023

from MPU6050 import MPU6050
from BMP280 import BMP280,BMP280_PRES_OS_16

from os import listdir, chdir
from machine import Pin, SoftI2C
from servo import Servo
import time
import math

class Pins:
    D0, D1, D2 = 0, 1, 2
    D3, D4, D5 = 21, 22, 23
    D6, D7 = 16, 17
    D8, D9, D10 = 19, 20, 18

# SETUP I2C and connected devices
SDA = Pin(Pins.D2)
SCL = Pin(Pins.D5)

i2c = SoftI2C(sda=SDA, scl=SCL, freq=100000)

mpu = MPU6050(i2c)
bmp = BMP280(i2c, use_case=BMP280_PRES_OS_16)

print(f"devices set up! i2c scan: {i2c.scan()}")

x_servo = Servo(Pins.D7)
x_servo_max = 100
y_servo = Servo(Pins.D9)
y_servo_max = 130
buzzer = Pin(Pins.D0, Pin.OUT)

# Globals
last_time = time.ticks_ms()
alpha = 0.98
roll, pitch, yaw = 0, 0, 0

alt_measurements = []

def clamp(val, lower, upper):
    return max(min(val, upper), lower)

class MultipurposePID:
    def __init__(self, KP, KD, KI, KI_MAX, MIN = None) -> None:
        '''
        Create a multipurpose PID that has individually tuned control variables.

        Args:
            KP (int): kP value for tuning controller
            KD (int): kD value for tuning controller
            KI (int): kI value for tuning controller
            KI_MAX (int): integral will not be allowed to pass this value
            MIN (int): a minimum value that the PID will output

        Returns:
            None
        '''
        
        self.kP, self.kD, self.kI = KP, KD, KI
        self.kI_max = KI_MAX
        self.error = 0
        self.integral = 0
        self.integral_processed = 0
        self.derivative = 0
        self.last_error = 0
        self.minimum = MIN
    def calculate(self, TARGET, INPUT) -> int:
        '''
        Calculates the output based on the PID's tuning and the provided target & input

        Args:
            TARGET (int): a number that the PID will try to reach
            INPUT (int): the current sensor or other input

        Returns:
            PID outpit (int)
        '''
        self.error = TARGET - INPUT

        if self.kI != 0:
            self.integral += self.error

            if self.integral > 0:
                self.integral = min(self.integral, 5 / self.kI)
            else:
                self.integral = max(self.integral, 5 / self.kI * -1)
            self.integral_processed = self.integral * self.kI

            if self.kI_max is not None:
                if self.integral_processed > 0:
                    self.integral_processed = min(self.integral_processed, self.kI_max)
                else:
                    self.integral_processed = max(self.integral_processed, self.kI_max * -1)

        self.derivative = (self.error - self.last_error) * self.kD
        
        output = (self.error * self.kP) + self.integral_processed + self.derivative
        if self.minimum is not None:
            if abs(output) < self.minimum:
                if self.error < 0: output = -self.minimum
                else: output = self.minimum
        
        self.last_error = self.error

        return output

class FlightController:
    def __init__(self) -> None:
        self.gyro_offsets = [0.0, 0.0, 0.0]
        self.pressure_baseline = 0.0
        self.last_orientation_time = None
        
        self.roll, self.yaw, self.pitch = 0.0, 0.0, 0.0
        print("Created flight controller object")

    def calibrate(self, calibration_time: int = 10):
        print("Calibrating IMU & altimeter")

        offsets = [0.0, 0.0, 0.0]
        baseline_pressure = 0
        
        num_measurements = 0
        end_loop_time = time.time() + calibration_time
        while time.time() < end_loop_time:
            num_measurements += 1
            offsets += self.get_gyro()
            baseline_pressure += bmp.pressure
        
            time.sleep(0.05)
        
        print(f"Sensor calibration complete. Collected {num_measurements} points")
        self.gyro_offsets = [i/num_measurements for i in offsets]
        self.pressure_baseline = baseline_pressure / num_measurements

    def update_orientation(self):
        ax, ay, az = self.get_accel()
        gx, gy, gz = self.get_gyro()
        

        now = time.ticks_ms()
        if not self.last_orientation_time: self.last_orientation_time = now
        
        dt = (time.ticks_diff(now, self.last_orientation_time )) / 1000
        self.last_orientation_time  = now

        # convert gyro deg/s -> rad/s
        gx = math.radians(gx - self.gyro_offsets[0])
        gy = math.radians(gy - self.gyro_offsets[1])
        gz = math.radians(gz - self.gyro_offsets[2])

        # --- gyro integration ---
        self.roll += gx * dt
        self.pitch += gy * dt
        self.yaw += gz * dt

        # --- accel angles ---
        accel_roll = math.atan2(ay, az)
        accel_pitch = math.atan2(-ax, math.sqrt(ay*ay + az*az))

        # --- complementary filter ---
        self.roll = alpha * self.roll + (1 - alpha) * accel_roll
        self.pitch = alpha * self.pitch + (1 - alpha) * accel_pitch

        self.max_altitude = 0


    @staticmethod
    def get_gyro():
        gyro = mpu.read_gyro_data()   # read the gyro [deg/s]
        assert gyro
        return gyro["x"], gyro["y"], gyro["z"]

    @staticmethod
    def get_accel():
        accel = mpu.read_accel_data()
        assert accel
        return accel["x"], accel["y"], accel["z"]
    
    @staticmethod
    def update_servo(deg: float | int, servo: Servo, msg: bool = False):
        if msg: print(f"spinning servo to {deg} deg")
        servo.write(deg)

    def get_altitude(self):
        R = 287.05
        T = bmp.temperature + 273.15
        g = 9.80665
        k = R * T / g
        relative_alt = k * math.log(self.pressure_baseline / bmp.pressure)
        
        alt_measurements.insert(0, relative_alt)
        if len(alt_measurements) >= 10:
            alt_measurements.pop()
        
        return sum(alt_measurements) / len(alt_measurements)

    @staticmethod
    def beep(sound_time: float = 0.05):
        buzzer.on()
        time.sleep(sound_time)
        buzzer.off()

    def circle_servo_test(self, duration: int = 10):
        last_time = time.ticks_ms()
        elapsed_time = 0
        
        while elapsed_time < duration:
            elapsed_time += time.ticks_diff(time.ticks_ms(), last_time) / 1000
            last_time = time.ticks_ms()
            
            y_pos = (math.sin(elapsed_time * 3.0)+ 1.0) / 2
            self.update_servo(y_pos * y_servo_max, y_servo)

            x_pos = (math.cos(elapsed_time * 3.0)+ 1.0) / 2
            self.update_servo(x_pos * x_servo_max, x_servo)
            # print(y_pos, x_pos)

    def run_timed(self, duration: int = 20):
        start_time = time.ticks_ms()
        print(f"Running {duration}s timed run")
        # self.beep()
        time.sleep(0.5)
        self.beep(0.1)
        
        self.update_servo(x_servo_max / 2, x_servo)
        self.update_servo(y_servo_max / 2, y_servo)
        
        # timed vars
        last_time = time.ticks_ms()
        elapsed_time = 0

        x_pid = MultipurposePID(0.3, 0.01, 0.0, 0.0)
        y_pid = MultipurposePID(0.3, 0.01, 0.0, 0.0)
        
        while elapsed_time < duration:
            elapsed_time += time.ticks_diff(time.ticks_ms(), last_time) / 1000
            last_time = time.ticks_ms()
            
            self.update_orientation()
            
            # self.pitch and self.roll are from -1.5 to 1.5 (1.5 being 90 degrees, so if it gets that bad we cant do anything)
            # normalize raw pitch and roll data to be from 0 to max servo angle

            # print((self.pitch + 1.5) / 3.0)
            # print(x_servo_max)
            normalized_pitch = ((self.pitch + 1.5) / 3.0) * x_servo_max
            normalized_yaw = ((self.roll + 1.5) / 3.0) * y_servo_max
                        
            x_out = x_pid.calculate(x_servo_max / 2, normalized_pitch)
            y_out = y_pid.calculate(y_servo_max / 2, normalized_yaw)
            
            x_target = x_servo.read() + x_out
            y_target = y_servo.read() + y_out
            # self.update_servo(x_out, x_servo)
            self.update_servo(clamp(x_target, 0, x_servo_max), x_servo)
            self.update_servo(clamp(y_target, 0, y_servo_max), y_servo)
            # print(x_target)
            # print(self.pitch, self.roll)
            alt = self.get_altitude()
            self.max_altitude = max(alt, self.max_altitude)
        
        print("Timed run complete, beeping.")
        self.beep()
        
        print("Writing data to flight log.")
        with open("log.txt", "w") as f:
            f.write(f"max alt: {self.max_altitude}\n")
            f.write(f"Start time: {start_time}ms\n")
            f.write(f"End time: {str(time.ticks_ms())}ms\n")
            f.write(f"Elapsed time: {str(time.ticks_diff(time.ticks_ms(), start_time))}")
        print("Done writing data!")
    
    def run(self):
        self.beep()
        
        # servo test
        # print("testing servo motors")
        
        self.update_servo(x_servo_max // 2, x_servo)
        self.update_servo(y_servo_max // 2, y_servo)

        x_pid = MultipurposePID(0.1, 0.0, 0.0, 0.0)

        # self.update_servo(0, servo1)
        # self.update_servo(0, servo2)
        # self.update_servo(x_servo_max//2, x_servo)
        # self.update_servo(y_servo_max, x_servo)
        # self.update_servo(y_servo_max//2, y_servo)

        # time.sleep(1)
        # # self.update_servo(125, servo1)
        # self.update_servo(125//2, servo1)
        # time.sleep(2)
        # # self.update_servo(0, servo1)
        # time.sleep(1)
        # self.update_servo(90, servo2)
        # time.sleep(2)
        # self.update_servo(0, servo2)
        # time.sleep(1)
        # self.update_servo(50, servo2)
        # time.sleep(1)
        # self.update_servo(180, servo2)
        # time.sleep(1)
        # self.update_servo(0, servo2)
        
        # print('started')
        # while True:
        #     print(bmp.temperature)

        # while True:
        #     try:
        #         # self.update_orientation()
                
        #         # print(f"{self.roll}, {self.pitch}, {self.yaw}, {self.get_altitude()}")

        #         # # Rough Temperature
        #         # temp = mpu.read_temperature()   # read the device temperature [degC]
        #         # print("Temperature: " + str(temp) + "°C")

        #         # # G-Force
        #         # gforce = mpu.read_accel_abs(g=True) # read the absolute acceleration magnitude
        #         # print("G-Force: " + str(gforce))
                
        #         time.sleep_ms(100)
        #     except KeyboardInterrupt:
        #         print("stopped")
        #         break
        
        print("done")

if __name__ == "__main__":
    con = FlightController()
    con.beep()
    con.calibrate(5)
    # con.run()
    # con.circle_servo_test(10)
    con.run_timed(10)
    con.beep()

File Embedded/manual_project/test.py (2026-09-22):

# Example code for (GY-521) MPU6050 Accelerometer/Gyro Module
# Write in MicroPython by Warayut Poomiwatracanont JAN 2023

# from MPU6050 import MPU6050
from BMI160 import BMI160

from os import listdir, chdir
from machine import Pin, I2C, SoftI2C
from time import sleep_ms

# i2c = I2C(0, sda=Pin(22), scl=Pin(23), freq=400000)
i2c = SoftI2C(sda=Pin(22), scl=Pin(23), freq=400000)
IMU = BMI160(i2c, addr=105)
print(f"devices set up! i2c scan: {i2c.scan()}")
print(IMU.read_gyro_raw())

IMU.initialize()

IMU.set_gyro_offset_enabled(True)

IMU.auto_calibrate_gyro_offset()
IMU.set_gyro_range(250)
IMU.set_gyro_rate(100.0)

rotation = [0.0, 0.0, 0.0]

while True:
    try:
        # Accelerometer Data
        gyro = IMU.read_gyro() # read the accelerometer [ms^-2]
        assert gyro is not None
        rotation[0] += gyro[0] / 100
        rotation[1] += gyro[1] / 100
        rotation[2] += gyro[2] / 100
        print("{:.2f}, {:.2f}, {:.2f}".format(*rotation))
        # aX = accel["x"] # type: ignore
        # aY = accel["y"] # type: ignore
        # aZ = accel["z"] # type: ignore
        # print("x: " + str(aX) + " y: " + str(aY) + " z: " + str(aZ))

        # Gyroscope Data
        # gyro = mpu.read_gyro_data()   # read the gyro [deg/s]
        # gX = gyro["x"]
        # gY = gyro["y"]
        # gZ = gyro["z"]
        # print("x:" + str(gX) + " y:" + str(gY) + " z:" + str(gZ))

        # Rough Temperature
        # temp = mpu.read_temperature()   # read the device temperature [degC]
        # print("Temperature: " + str(temp) + "°C")

        # G-Force
        # gforce = mpu.read_accel_abs(g=True) # read the absolute acceleration magnitude
        # print("G-Force: " + str(gforce))

        # Time Interval Delay in millisecond (ms)
        sleep_ms(10)
    except KeyboardInterrupt:
        print("finish")
        break

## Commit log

2026-05-18 torque from engine gimbal on rocket
2026-06-17 `simulation.py` more robust rocket simulation - time control and step counting - dynamic thrust based on engine thrust curve - TVC engine angle simulation
    [thrust_curve_D.csv, thrust_curve_E.csv]
2026-06-17 config.hjson - hot reloading of configuration options - more extensive suite of control options - note rocket max height (⚠️ probably need to figure out proper units and scalaing for all simulation a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
2026-06-19 Joined simulation repo with all other related project files (embedded software, CAD, media, etc.) for portfolio
    [BodyGimbalMount.SLDPRT, BodyGimbalMount.STEP, BodyTube.SLDPRT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]
2026-09-20 CAD components updated to SW2026 (rolling process, will not note in every further commit)
    [BodyGimbalMount.SLDPRT, BodyTube.SLDPRT, Clevis_pin.SLDPRT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]
2026-09-20 Additional CAD Components - Rough model of flight computer + Battery to design sled - Rough nosecone model
    [Battery.SLDPRT, FlightComputer.SLDPRT, FlightComputerSled.SLDASM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]
2026-09-20 Updated flight computer software to work with perfboard assembly
2026-09-20 Removed pygame-ce rocket simulation - Decision reasoning detailed in simulation documentation - Retained thrust curve data from Estes for D and E motors, as well as rocket specifications information 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
2026-09-20 CAD Updates
    [BodyGimbalMount.SLDPRT, Inner Gimbal.SLDPRT, MotorMount.SLDPRT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]
2026-09-21 Added airframe spacers to CAD
    [BodyGimbalMount.SLDPRT, BodyTube.SLDPRT, LargeBodyTubeSpacer.SLDPRT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]
